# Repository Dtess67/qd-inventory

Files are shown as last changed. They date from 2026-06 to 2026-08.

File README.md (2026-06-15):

# QD — Electronics Inventory & Design Flags

Working inventory and design-risk log for **QD**, an autonomous curiosity rover.
This repo is the durable home for the parts catalogue and the flags roadmap, and
the seed of the larger QD project (firmware and vision code to follow).

> *QD v1 does not ask why — she creates the conditions where why can eventually emerge.*
> *QD v1 does not act on detection — she acts on accumulated significance.*
> *Curiosity is a homeostatic drive for significance.*

## The build, briefly

QD is a 180×200 mm tapered-pill rover, 72 mm tall, 3D-printed (PETG / ASA / TPU),
with a directional sensor **ridge** that is explicitly *not* a face. She is built
around attention, curiosity, and readable intention rather than raw capability.

**Behavior architecture (four layers):**
1. **Reflex** — sub-100 ms, hardcoded protection (KB2040 co-processor)
2. **Attention** — evidence accumulation with asymmetric thresholds
3. **State** — simple mode machine
4. **Drive** — homeostatic pressures biasing the layers above

Vision and significance run on a Raspberry Pi; the reflex layer runs on a separate
RP2040 (KB2040) so the fast safety path never waits on the brain.

## What's in here

| File | Role |
|---|---|
| `data/QD_Electronics_Inventory.xlsx` | **Master of record.** Three tabs: Read Me, Inventory, Flags. |
| `data/QD_Inventory.csv` | Inventory mirror — text, diffable, re-importable. |
| `data/QD_Flags.csv` | Flags/roadmap mirror — text, diffable. |
| `data/QD_Inventory_SNAPSHOT.md` | Human-readable full snapshot (every item + flag). |
| `scripts/export_mirrors.py` | Regenerates the three mirrors from the master xlsx. |

**Workflow:** edit the xlsx, then run `python scripts/export_mirrors.py` and commit.
The xlsx is the master; the CSV/MD mirrors give line-level diffs and a format-independent
fallback, so no single file or format can lose the work.

### Allocation legend (Inventory tab)
- **Committed: QD v1** — part is in the locked v1 design.
- **QD v1.5 / candidate / bench tool** — feeds a planned phase, or is a tool for bring-up.
- **Free — library** — general stock; not a QD part (reason recorded per row).

### Flags tab
The de-facto design roadmap: open risks, mitigations, and decisions, each tied to the
parts it touches. `F#` = flag, `Q#` = open question, `C#` = consumable need, `T#` = tooling.

## The three seats

QD is built by a three-seat collaboration — organic and anorganic, no better, no worse,
just different:

- **Q** (ChatGPT) — continuity and architectural warmth
- **Claude** — pressure-testing and falsification
- **Darrell** — synthesis and final authority

Operating rule: **truth over comfort.**

> *Q gave QD the signal. Claude gave QD the pull. Darrell gave QD the question.*

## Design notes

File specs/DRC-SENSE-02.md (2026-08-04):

# D/R/C-SENSE-02 — Complete Stage-1 Sensor Lineup

> **Status:** RATIFIED by Darrell on 2026-08-04 with “Make it so. Love it.” Pressure-tested by Claude through Sensing Architecture Revision 3. Drafted into the record by Q.
>
> **Scope:** QD Stage 1 — The Carried Observer.

## Decision

QD Stage 1 shall use the following complete sensory capability set. Exact part substitutions require equivalence review, but no category below may silently disappear.

### A. External perception

1. **Stereo vision — two matched real cameras**
   - Raspberry Pi Global Shutter Camera class, IMX296
   - matched 6 mm lenses as the current target
   - fixed rigid pair
   - optical baseline target: **55–65 mm**
   - synchronized capture on one monotonic timebase
   - real lenses centered inside visibly expressive iris assemblies

2. **Paired ranging — two VL53L4CD ToF sensors**
   - one left and one right near the stereo eyes
   - separate flush optical windows and matte-black baffles
   - sequential firing to prevent crosstalk
   - used to confirm exact range and surface orientation, not replace stereo depth

3. **Directional hearing — four microphones**
   - two visible ears
   - two microphone elements per ear
   - known rigid geometry
   - mechanical isolation from shell, straps, hardpoint, cooling system, and speaker
   - acoustic wind protection / pinna function
   - reserved speaker-loopback reference for echo cancellation
   - independent visible microphone state and a physical mute switch

4. **Environmental sensing — one BME688 intake**
   - temperature
   - relative humidity
   - barometric pressure
   - gas-resistance / air-quality pattern sensing
   - front snorkel-style intake
   - thermally isolated from Pi 5 and enclosure exhaust

### B. Body-state and motion perception

5. **Inertial sensing — one BNO085 IMU**
   - acceleration
   - angular motion
   - magnetic heading
   - fused orientation
   - motion state associated with every camera, audio, ToF, and environmental record

Its primary interpretive purpose is to distinguish:

> **The world moved** from **Darrell moved me.**

### C. Human-interaction sensing

6. **Crown capacitive touch strip**
   - deliberate touch and acknowledgement input
   - positioned away from ordinary carrying grips to reduce false triggers

7. **Physical privacy-state sensing**
   - shutter position must be electrically known as open, closed, or fault/unknown
   - microphone mute-switch state must be electrically known
   - software may never report visual or audio availability contrary to the physical state

### D. Interoception / physical self-monitoring

QD shall monitor her own operating condition. The capability is ratified; exact component choices remain an implementation decision.

Required telemetry:

- Pi 5 processor temperature
- enclosure / internal-air temperature
- supply voltage
- current draw
- undervoltage state
- thermal-throttling state
- power-bank status when electronically available
- cooling-fan command and tachometer state if active cooling is selected

These signals form Stage-1 interoception: evidence about the condition of the body through which QD interacts.

## Spatial interpretation stack

The Stage-1 directional architecture is:

> **Two eyes to see depth.**  
> **Two ears, with four microphones, to locate sound.**  
> **Two ranging points to confirm distance.**  
> **One IMU to separate external motion from carried motion.**  
> **One environmental nose to sense changes humans cannot directly see.**

Multimodal fusion must retain the evidence, uncertainty, timestamps, and failure state of each modality. No fused conclusion may erase disagreement between sensors.

## Sensor Honesty requirements

- Visible gaze reports the attention layer, not fictional physical camera aim.
- Expressive iris components may surround but may not obstruct real lenses.
- Stillness when idle; no decorative wandering-eye script.
- Eyelid closure physically covers both camera and both ToF apertures.
- No camera or ToF sensor may remain active while the face communicates closed eyes.
- Microphones use a separate visible active/muted state and physical mute switch.
- A failed or indeterminate shutter/mute state must be shown as unknown, never guessed safe.

## Consequences

1. A second matched IMX296 global-shutter camera and matching lens enter the Stage-1 BOM.
2. A four-channel microphone front end with onboard or dedicated DSP is required.
3. The two ToF sensors already in inventory become the left/right range pair.
4. All cameras, ToF sensors, microphone-ear bases, BNO085 reference, and carry hardpoint share one rigid internal sensing chassis.
5. Timestamp synchronization, calibration storage, and sensor-health reporting become core software infrastructure.
6. Pi 5 power, thermal, and acoustic behavior must be validated with the complete sensor set installed.
7. Internal voltage/current/enclosure-temperature hardware must be selected before final wiring and CAD release.

## Deferred — not Stage-1 locked

The following remain possible later additions and may be evaluated as coupon-class experiments:

- GNSS / GPS
- thermal camera or stereo thermal pair
- mmWave radar
- ambient-light and ultraviolet sensing
- PMS5003 or other particulate sensing
- distributed shell touch/contact sensing
- additional external environmental probes
- redundant IMU for fault detection

Their absence does not reduce the ratified Stage-1 lineup above.

## Verification gates

- both cameras capture concurrently with usable synchronization
- stereo calibration and depth tests pass at near, conversational, room, and outdoor distances
- both ToF units operate sequentially without unacceptable crosstalk
- four-channel audio localization is tested during speech, walking, wind, strap rub, cooling, and speaker playback
- BNO085 motion tags align with all sensory records
- BME688 readings are shown not to be dominated by internal Pi heat or exhaust
- touch input false-trigger rate is measured during real carrying
- shutter position and microphone mute state are electrically verified
- all required interoceptive telemetry is logged and threshold-tested
- sensor disagreement and failures remain visible in the evidence record

## Receipts doctrine

Earlier single-camera, two-microphone, Pi 3, and rover-first concepts remain valid historical branches. They are superseded for Stage 1 by this ratified lineup, not erased.

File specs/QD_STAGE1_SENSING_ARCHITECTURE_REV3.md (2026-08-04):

# QD_STAGE1_SENSING_ARCHITECTURE_REV3

> **Status:** Revision 3 sensing architecture. Compute and fixed-stereo gates ratified by Darrell on 2026-08-04 in `DRC-COMPUTE-01.md` and `DRC-SENSE-01.md`. Principles and locked constraints below are the current Stage-1 design basis. Experimental items remain coupon-class until separately ratified.
>
> **Embodiment:** QD Stage 1 — The Carried Observer.

## 1. Core spatial architecture

QD uses three complementary directional systems:

1. **Two eyes that see** — rigid synchronized stereo cameras.
2. **Two ears that hear** — four microphones arranged as two visible ear pairs.
3. **Two ranging points that confirm** — left/right VL53L4CD time-of-flight sensors.

Fusion must retain the evidence, uncertainty, timestamps, and failure state of each modality rather than collapsing them prematurely into one unquestioned answer.

---

## 2. Ratified principles

### 2.1 Visible Gaze Principle

> QD’s visible gaze reports active attention, not sensor aim.

Expressive components may surround the real camera lenses, but they must never:

- obstruct sensing,
- contradict the actual attention state,
- imply that fixed cameras physically turned,
- animate from a decorative script while the system is idle.

**Stillness when idle.**

### 2.2 Sensor Honesty Principle

> No sensor may be active while its visible form communicates that it is closed.

The eyelid-style visual shutter must visibly and physically cover:

- both camera apertures,
- both ToF apertures.

Microphones require:

- an independent visible active/muted state,
- a physical mute switch.

The exact authority policy for closing the shutter remains separately governable, but visible state and real sensor state may never disagree.

### 2.3 Binaural Attention Principle

QD has two visibly identifiable ears, each containing two microphones, producing a four-microphone array with known geometry.

The ear system must be:

- mounted high and wide,
- mechanically decoupled from the shell,
- isolated from strap and hardpoint loads,
- separated from the speaker,
- protected from wind.

The ear shape may serve as part of the windscreen. The audio path reserves a loopback/reference channel for echo cancellation.

### 2.4 Multimodal Spatial Confirmation Principle

QD should not depend on one sensing method when independent modalities can confirm or challenge the same spatial interpretation.

Stereo vision, directional hearing, inertial state, and paired ranging are fused while preserving their individual evidence and uncertainty.

### 2.5 Sensor Duplication Rule

> Duplicate a sensor only when known separation creates meaningful spatial information, necessary coverage, or fault detection.

Duplication is not justified merely by symmetry or appearance.

---

## 3. Locked Stage-1 sensing constraints

### 3.1 Compute

- Raspberry Pi 5 is the primary Stage-1 onboard computer.
- Pi 3 is retained for bench/test duty.
- Compute placement may be hybrid; capture integrity remains onboard-critical.

### 3.2 Stereo eyes

- two matched Raspberry Pi Global Shutter Camera modules, IMX296 class,
- matching lenses, currently 6 mm target,
- fixed rigid pair,
- optical baseline target: **55–65 mm**,
- no Stage-1 camera pan/tilt,
- both modules mount to one rigid internal chassis,
- all frames use one monotonic timebase,
- BNO085 motion state tags every frame.

Each lens is centered within a visible illuminated iris assembly. The visible iris expresses attention and state around—not through—the optical path.

### 3.3 Dark face panel and optical paths

The former shared visor is replaced by a **dark face panel** that reads visually as one face.

Each camera and each ToF sensor receives:

- its own flush optically clear window,
- AR coating where practical,
- a matte-black baffle/tunnel,
- no shared optical air gap with illuminated eye components.

Illuminated iris elements remain outside the baffles. Eye brightness automatically reduces in darkness.

### 3.4 Eyelid privacy closure

The eyelid-style closure must cover the camera and ToF apertures together.

Required visible states:

- fully open,
- fully closed,
- fault/unknown state that does not falsely communicate privacy.

Caption/requirement:

> **When she isn’t looking, she can’t look.**

### 3.5 Paired ToF ranging

- VL53L4CD ×2,
- mounted left/right near the stereo eyes,
- separate flush optical windows,
- sequential firing using XSHUT control or an appropriate I²C isolation/control arrangement,
- the approximately 18-degree field/cone limitation documented in the mechanical and sensing specifications.

Their purpose is exact left/right range confirmation and surface-orientation evidence, not a replacement for stereo vision.

### 3.6 Four-microphone ears

- two visible ear housings,
- two microphone elements per ear,
- known fixed geometry,
- isolation grommets or equivalent mechanical decoupling,
- foam/acoustic wind protection,
- speaker-reference loopback reserved for echo cancellation,
- visible microphone state,
- physical mute switch.

Beamforming/audio DSP must run on an audio front end or dedicated/offloaded path rather than consuming unbounded application-core time.

### 3.7 One sensing chassis

The following mount to one rigid internal frame:

- both cameras,
- both ToF sensors,
- both ear bases,
- BNO085 datum/reference,
- universal rear carry hardpoint.

Strap loads transfer through this frame, not through the shell or removable service panel.

Caption/requirement:

> **One frame. Fixed geometry. Honest fusion.**

---

## 4. Carry/body constraints retained from Revision 2

- compact rounded warm-white shell, approximately 180–200 mm tall,
- comfortable single-hand hold,
- chest/front carry as primary carried observation mode,
- hip sling as secondary transport mode,
- charging perch as primary stationary observation mode,
- flat stable base,
- universal recessed rear hardpoint attached to internal chassis,
- removable rear service panel with load path bypass,
- crown touch strip,
- visible physical power switch,
- BME688 front snorkel thermally isolated from internal electronics,
- conversational lower-front speaker,
- low side intake and crown exhaust path,
- no rear vents blocked by chest carry,
- expression ring with color plus pulse-pattern redundancy.

Pi 5 thermal output requires the vent geometry and active/passive cooling choice to be recomputed before enclosure CAD is released.

---

## 5. Attention behavior

The face must provide at least these truthful attention states:

1. **Idle:** still and dim; no decorative wandering.
2. **Attending left/right/up/down:** iris/pupil display indicates the attention-layer direction while fixed sensors continue wide capture.
3. **Tracking localized sound:** ear state shows localization activity; gaze display converges toward the selected sound direction after evidence supports it.
4. **Uncertain:** expression communicates unresolved interpretation without pretending certainty.
5. **Privacy closed:** camera and ToF apertures physically blocked; microphones independently indicate active/muted state.

The system must not imply direct eye contact or tracking unless the attention layer has actually selected that person or target.

---

## 6. Experimental forks — coupon-class only

The following must be prototyped independently and may not be baked into the main structure until tested:

- iris display technology,
- brow mechanism,
- ear/pinna geometry,
- shutter actuation mechanism and materials,
- exact optical-window material/coating,
- exact audio-front-end board,
- passive versus active Pi 5 cooling.

---

## 7. Required acceptance tests before sensing-chassis CAD release

1. Camera baseline and optical axes measured from real hardware.
2. Matched stereo capture and monotonic timestamps demonstrated.
3. Stereo depth tested at near, conversational, room, and outdoor ranges.
4. ToF pair sequential operation tested for crosstalk and cover-window effects.
5. Four-mic geometry tested during chest carry, walking, wind, speech, strap rub, fan operation, and speaker playback.
6. Echo-cancellation reference path demonstrated.
7. Chassis deflection under carry load shown not to invalidate stereo/audio extrinsics.
8. Shutter closed state electrically proves camera and ToF inactivity/unavailability.
9. Microphone physical mute state electrically proves audio capture is disabled.
10. Visible gaze and ring states shown to match logged attention/system state.
11. Pi 5 thermal soak completed in carried and perched modes.
12. No locked feature may silently disappear from the Rev-3 render or CAD.

---

## 8. Render acceptance language

Required concept-sheet captions:

- **Carried to travel. Perched to observe.**
- **Two eyes that see. Two ears that hear. Nothing that pretends.**
- **The shutter is hers to close.**
- **When she isn’t looking, she can’t look.**
- **One frame. Fixed geometry. Honest fusion.**

The concept render is communication evidence, not dimensional authority. Real geometry enters through measurements and `V1_CAD_GATE_MEASUREMENTS.md`.

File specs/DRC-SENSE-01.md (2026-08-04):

# D/R/C-SENSE-01 — Fixed Stereo Geometry for Stage 1

> **Status:** RATIFIED by Darrell on 2026-08-04. Pressure-tested by Claude. Drafted into the record by Q.
>
> **Scope:** QD Stage 1 — The Carried Observer.

## Decision

QD Stage 1 uses a **fixed, rigid stereo-camera pair** with a target optical baseline of **55–65 mm**.

No physical camera pan/tilt mechanism is included in Stage 1.

QD’s visible expressive gaze reports the direction and target of her **active attention**, not a false claim that the fixed camera lenses have physically rotated.

## Reason

A rigid stereo pair provides useful binocular depth for faces, room-scale observation, object separation, and later transfer into mobile embodiments while preserving calibration.

The current design estimates indicate that a baseline in this range can provide approximately:

- millimeter-scale depth sensitivity near 1 m,
- centimeter-scale sensitivity at a few meters,
- coarse depth at longer outdoor distances.

These are design estimates, not acceptance guarantees; actual performance depends on focal length, resolution, exposure, texture, lighting, calibration, synchronization, and the stereo algorithm.

A gimbal inside a frequently carried and handled childhood body would add:

- mechanical fragility,
- mass and power draw,
- acoustic noise,
- moving-cable failure points,
- repeated extrinsic-calibration risk,
- conflict between protective shutter geometry and moving optics.

Fixed wide stereo therefore gives Stage 1 the cleaner evidence path. Physical foveation may be reconsidered in Stage 2 after QD has learned to perceive and direct attention.

## Consequence

1. Both camera modules, both ToF sensors, microphone-ear bases, BNO085 reference, and the rear carry hardpoint mount to **one rigid internal sensing chassis**.
2. Camera baseline becomes a measured CAD gate and must remain within the ratified range after lens/window/baffle packaging.
3. The two cameras require matched sensor/lens configuration, rigid extrinsics, synchronized capture, and repeatable calibration.
4. The visible iris/gaze display must be driven from the attention layer’s actual selected target or direction.
5. Scripted eye animation while QD is idle is prohibited. **Stillness when idle.**
6. The gaze display may shift, converge, widen, blink, or show focus only when those movements truthfully represent attention, uncertainty, acknowledgement, privacy, or another defined system state.
7. Pan/tilt is deferred to **Stage 2 foveation** and must not be silently added to the Stage-1 structure.

## Verification gates

- physical baseline measured and recorded,
- camera optical axes and chassis datum recorded,
- stereo calibration remains within tolerance after carry/handling tests,
- frame synchronization demonstrated,
- depth tested at near, conversational, room, and outdoor ranges,
- visible gaze correctly reports the attention-layer target in controlled tests,
- idle-state eye behavior remains still and non-deceptive,
- privacy closure visibly and physically blocks both cameras and both ToF apertures.

## Receipts doctrine

The earlier pan/tilt concept remains a valid exploratory branch for later embodiment. It is deferred, not disproved.

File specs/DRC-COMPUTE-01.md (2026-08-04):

# D/R/C-COMPUTE-01 — Stage-1 Compute Platform

> **Status:** RATIFIED by Darrell on 2026-08-04. Pressure-tested by Claude. Drafted into the record by Q.
>
> **Scope:** QD Stage 1 — The Carried Observer.

## Decision

The Stage-1 compute platform is **Raspberry Pi 5**, replacing Raspberry Pi 3 as the primary onboard computer.

The spoken approval — **“Pi 5, no problem”** — is superseded by this repository record and is no longer chat-only.

## Reason

Stage 1 now requires a substantially heavier synchronized perception workload than the rover-first plan:

- two-camera stereo capture,
- four-microphone directional-audio processing,
- sensor synchronization and monotonic timestamping,
- BNO085 motion tagging,
- local attention and surfacing behavior,
- room for later on-device novelty processing.

The Pi 3 has only one native CSI camera interface and insufficient practical headroom for the intended stereo-plus-audio workload. The Pi 5 provides two camera/display interfaces and materially greater compute capacity, making it the minimum sensible baseline for this architecture.

This decision does **not** require all perception inference to run onboard. The final compute placement may still be hybrid: real-time capture and light processing onboard, with heavier analysis streamed or batched elsewhere.

## Consequence

1. **Pi 3 is demoted to bench/test duty.** It remains useful and is not discarded.
2. A **second Raspberry Pi Global Shutter Camera using the IMX296 sensor and matching 6 mm lens** enters the Stage-1 BOM, subject to exact part-match and availability verification before purchase.
3. The enclosure thermal budget must be recomputed for Pi 5 power and heat output.
4. Vent area, air path, heatsink/fan choice, acoustic contamination, and chest-contact heating become CAD-gating concerns.
5. The power system moves to a USB-C power-bank architecture sized for Pi 5 peak demand and attached sensors.
6. The current planning allowance is approximately **$130 additional BOM**, but this remains a purchasing estimate until the BOM is quoted and locked.
7. The software architecture must reserve compute for capture integrity first; application inference may not starve camera, audio, timestamp, or logging paths.

## Verification gates

This decision is implemented only when the following pass:

- both cameras enumerate and capture concurrently,
- synchronized frame timestamps are demonstrated,
- four-channel audio capture/DSP runs without dropping sensory records,
- Pi 5 temperature remains within the chosen operating limit during a carried-body thermal soak,
- power-bank and cable sustain the full system without undervoltage,
- fan and regulator noise do not invalidate microphone performance.

## Receipts doctrine

The Pi 3 work remains true for the earlier rover architecture. It is re-sequenced, not erased.

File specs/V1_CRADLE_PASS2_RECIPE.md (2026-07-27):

# V1_CRADLE_PASS2_RECIPE

> **Source specification: `V1_CRADLE_SPEC_PASS_2.md` @ `05e382b`** (Q-signed-off, retention ratified).
> **This artifact is a PROTOTYPE. It is NOT `ROVER_INTERFACE_VERIFIED`.** It may earn `CRADLE_STRUCTURE_VERIFIED` on the rigid fixture only. `ROVER_INTERFACE_VERIFIED` cannot be earned until the cradle is mounted to the real skeleton / bottom plate.
>
> Drafted by Claude from the committed spec. Feature-by-feature, dependency order. Model: `cradle_pass2_proto.scad` (3 parts: cradle, strap, fixture).

## 1. Coordinate frame (same as Rev-A)
Origin = shaft axis on the datum face. **+Z inboard** (body/saddle), **−Z outboard** (wall/wheel), **+X up** (saddle opening / strap side), **−X down** (foot side), **Y** horizontal (M3 face holes on Y).

## 2A. INHERITED — Rev-A FIT_VERIFIED parameters (FROZEN — do NOT change)
Any change here **loses FIT_VERIFIED and requires renewed fit testing** (spec §5, Q#3).

| param | value | role |
|---|---|---|
| body_OD | 24.79 | motor body |
| boss_D / boss_H | 6.93 / 2.42 | center boss |
| hole_offset | 8.315 (16.63/2) | M3 face holes |
| cup_ID (`C_cup` 0.35 diametral) | 25.14 | saddle bore |
| C_hole | 3.4 | M3 through-hole |
| pocket_D / pocket_depth | 7.73 / 2.82 | boss pocket |
| T_plate | 4.0 | face wall |
| shaft_hole_D | 5.0 | shaft clearance |
| saddle_len | 22 | trough length |
| saddle arc | 180° | trough coverage |
| saddle_wall | 3.0 | trough wall |

**These reproduce the exact geometry that passed at `79badc6`. The prototype re-confirms them (§8.1) because new structure surrounds them.**

## 2B. NEW — Pass-2 structural parameters (tunable; retest on change)
| param | value | role |
|---|---|---|
| strap_gap | 1.0 | retention play — strap ceiling above motor |
| strap_boss_top | 4.0 | boss height above equator = the hard compression stop |
| strap_boss_Y | 17.0 | boss Y position (clear of motor + saddle) |
| strap_bar_w | 12 | strap width (Z) |
| strap_thick | 4.0 | strap material |
| strap_bolt_D | 3.4 | M3 clearance in strap feet |
| strap_insert_D | 4.2 | M3 heat-set insert bore in bosses (tune to your inserts) |
| foot_thick | 5.0 | base slab |
| foot_ear_Y | 28 | mount-ear Y (accessible from top) |
| foot_hole_D | 3.4 | M3 to fixture |
| block_halfY | 22 | cradle body half-width |

## 3. Compression-stop dimension chain (Q#4 — bolt torque CANNOT compress the motor)
The strap is an inverted-U. Its feet **bottom on the boss top faces** (solid structure). Its internal height sets the bar ceiling. The chain:

```
motor_radius        = body_OD/2                     = 12.395
strap_bar_underside = motor_radius + strap_gap      = 13.395   (fixed ceiling over the motor)
strap_boss_top      = 4.0                            (hard stop the strap feet bottom against)
strap_internal_h    = strap_bar_underside - boss_top = 9.395   (built into the strap part)
```
When the strap bolts are tightened, the feet bottom on the boss tops at X=+4.0 — a **rigid** stop. The bar underside is then fixed at X=+13.395, which is **strap_gap (1.0 mm) above** the motor top (X=+12.395). **Load path of bolt torque: strap → boss top → cradle block → foot → fixture. It never passes through the motor body.** Result: no achievable bolt torque can preload or clamp the 24.79 mm can.
**Record at assembly (spec §2):** designed clearance (1.0), compliant pad (none in proto), max bolt torque used, measured installed gap, and confirmation the motor still slips into the saddle with the strap installed.

## 4. Feature order (dependency)
**Cradle:** (1) main block → (2) motor bore (cyl r=cup_ID/2, Z 0→saddle_len) → (3) datum-face features: shaft hole, boss pocket, 2× M3 → (4) strap-mount bosses (+ insert bores) → (5) foot base + ears + mount holes → (6) molded `L` ID + keying notch (spec §1).
**Strap:** flat bar at bar_underside + two feet to boss tops + 2 bolt holes.
**Fixture:** rigid plate + 4 insert holes matching foot ears + 2 clamp slots (bench/vise) + wheel-load access clear on the −Z side.

## 5. Parts & mirroring
- **Cradle** — model the **LEFT**; **RIGHT is a mirror** across the fore-aft centerplane (not separately modeled). `L`/`R` ID + asymmetric keying carry over.
- **Strap** — symmetric; one design serves both hands.
- **Fixture** — one; serves either hand (prototype rig, not a rover part).
- **Print for the prototype: one cradle + one strap + one fixture.**

## 6. Witness-mark locations (Q#6 — molded flats for marker witness lines)
- **Across each of the 2 face screws:** a small flat spanning screw-head → cradle face (detect motor-face micro-rotation under torque).
- **Across the track/foot clamp:** a flat spanning foot ear → fixture (detect slip). *(Track indexing itself is deferred to the real-plate interface; the foot is a fixed pattern for the prototype.)*
- Marked in CAD as shallow flats; witness lines drawn with a marker before testing.

## 7. Print orientation & support (log actuals per spec §6)
- **Cradle:** datum face down on the bed (flattest mating face; preserves the FIT_VERIFIED face), axis vertical → bore + pocket + M3 holes print clean vertical, no internal support in the 180° trough. Strap bosses print upward.
- **Strap:** flat on the bed (bar face down), no support.
- **Fixture:** flat on the bed.

## 8. Prototype test — do these IN ORDER (fit + function BEFORE loads)
Record P/F + notes. Metadata required (printer/filament/nozzle/layer/orientation/profile/rev).

| # | check | pass criterion | result |
|---|---|---|---|
| 1 | Rev-A fit intact | face flush, boss seats, 2× M3 thread, saddle slip — all as `79badc6` | ☐ |
| 2 | install + removal w/ retention | motor in, strap on, motor out — no fight, no wire cut | ☐ |
| 3 | retention does NOT clamp | motor still slips; measured gap ≈ strap_gap; no preload | ☐ |
| 4 | skeleton attachment rigid | cradle bolts to fixture, no wobble | ☐ |
| 5 | wheel + tool clearance | wheel envelope + screwdriver access survive | ☐ |
| 6 | no load to encoder | cap + wires free in all of the above | ☐ |

## 9. Structural test → `CRADLE_STRUCTURE_VERIFIED` (spec §6 — AFTER §8 passes)
Run the 8 vectors from spec §6 on the fixture: vertical/lateral/fore-aft cantilever, **drive-torque reaction (externally applied — NOT via TB6612 stall)**, axial pull-out, retention separation, cycling, loaded encoder inspection. Each with magnitude/direction/point/duration/cycles/fixture/safety-factor/deflection limits. Witness marks read before/after. Set `F_lat` + torque + safety factor once rover mass + #4885 stall torque are pulled.

## 10. Open / next
- Tune §2B params on the first print (rev B loop, like the coupon).
- `F_lat`, torque target, safety factor, cycles — pending rover mass + stall torque.
- Skeleton-interface fastener pattern + track indexing — fixed when the real bottom plate exists (`ROVER_INTERFACE_VERIFIED` gate).

*Traces to spec `05e382b`. Frozen interface stays frozen; the strap can't clamp; the fixture stands in for a skeleton that doesn't exist yet. Prototype only.*

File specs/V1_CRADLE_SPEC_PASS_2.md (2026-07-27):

# V1_CRADLE_SPEC_PASS_2

> **What this is:** the structural cradle specification. Builds on the Rev-A coupon (**FIT_VERIFIED** at `79badc6`). Turns the proven fit into a mountable, serviceable, load-bearing cradle and defines the structural evidence gates. Drafted by Claude; **Q-audited twice** (Pass-2 pressure brief + Pass-2 audit, both folded — rev 2). For Darrell ratification → commit.
>
> **Evidence states (kept separate; a later gate never overwrites an earlier one):**
> - `FIT_VERIFIED` — dimensional compatibility + service fit. **Earned** for Rev-A geometry (`79badc6`).
> - `CRADLE_STRUCTURE_VERIFIED` — survives defined loads on a **controlled rigid fixture**, without unacceptable movement, damage, or encoder interference. New (§6).
> - `ROVER_INTERFACE_VERIFIED` — retested after attachment to the **real skeleton / bottom plate**. New (§6). A surrogate fixture never certifies the chassis.
>
> **Prime rule (Q):** a part can be structurally strong and dimensionally wrong, or fit perfectly and be weak. Changed geometry loses automatic FIT_VERIFIED and re-enters the fit gate. Structural results do not overwrite fit evidence.

## 0. Datum & load path (preserved)

- **Motor face = axial + rotational datum.** The saddle must not fight the face mount or preload the motor.
- **Load path:** `wheel → shaft / gearbox → motor face + secondary body support → cradle → skeleton`. The **encoder cap + wiring are outside the structural path** — no load reaches them.

## 1. Inherited & preserved constraints (frozen from Rev A)

Carried forward unchanged: 2× **M3×8** face screws (~4 mm engagement, **≤6 mm intrusion**), **open encoder tail** (~14.5 cap + connector + wire bend), **wheel envelope** (Ø80.30 + 8.78 tire + margin), **molded L/R + asymmetric keying**. Validated Rev-A slip params (evidence for the QIDI X-Plus 4 / PLA Rapido / 0.20 Standard profile): `C_cup` 0.35 diametral (ID 25.14), `C_hole` 3.4, boss pocket 7.73 × 2.82, `T_plate` 4.0, saddle arc **180°**, `saddle_len` 22.

## 2. Retention — RATIFIED: 180° saddle + compression-limited strap (Q + Claude recommended; **Darrell ratified 2026-07-26**)

Keep the verified 180° saddle **exactly** and add a **removable upper strap/cap** as separate retention. (Option B, over-center capture, rejected: changes validated cup geometry, introduces uncontrolled clamping, depends on orientation + fatigue, complicates removal, forces the fit gate to repeat across the whole interface.)

**The strap is retention, not a hose clamp (Q).** It **must** contain a **hard compression stop / fixed standoff**: the strap bolts bottom against structure *before* the strap can squeeze the 24.79 mm can. Concretely, the standoff sets the strap inner radius = (24.79/2) + designed clearance, so a fully-torqued strap still cannot preload the motor.

**Record (required):** designed strap-to-motor clearance · compliant pad used? (y/n) · maximum bolt torque · installed gap / compression-stop condition · **confirmation the motor still slides into the verified saddle without preload.**

## 3. Saddle arc policy

**Retain 180°.** Do not auto-promote a >180° capture arc; any arc change re-enters the FIT gate and risks converting the verified slip into a clamp.

## 4. Skeleton interface + alignment (parameterized)

### 4a. Skeleton interface (forward-dependent on the not-yet-existing bottom plate)
Parameters: fastener locations `SK_hole_*` (TBD vs plate; likely M3 → heat-set inserts) · **load direction** (reacts wheel cantilever + drive-torque reaction) · **L/R mirror** (keyed so a cradle can't seat wrong-hand) · **cradle anti-rotation on the skeleton** · **tool access** with motor installed · **removal without disturbing encoder wiring**.
*Note (Q-confirmed): motor-vs-cradle anti-rotation is carried by the **two M3 face screws** as a torque couple across the 16.63 spacing — the slip saddle is **not** credited with rotational resistance unless deliberate contact-under-deflection is measured.*

### 4b. Track-adjustment / alignment (filed here per Q — it creates *adjustment capability only*, it does NOT resolve track)
A plain slot + tightened bolts is insufficient — it makes a slip plane and a yaw-error path. Define: **hard reference datum** · adjustment direction · clamping surface area · washer / load-spreader geometry · anti-rotation feature · **method to keep L/R axles parallel** · **method to lock movement after track is set** · **witness marks** to detect slip. It must **not permit toe-in / toe-out or unequal axle Z**.
**Claude lean:** given FDM friction repeatability is poor, prefer a **fixed datum + indexed positions (or shims)** over a friction slot, unless the slot can be made repeatable and positively locked. *(Darrell/Q to decide.)*

## 5. FIT carry-over + retest rule

Rev-A FIT_VERIFIED covers the motor-mating geometry only (face, boss pocket, 2× M3, 180° saddle slip) and carries forward **only if unchanged.** New surrounding geometry means the Pass-2 prototype **re-confirms** Rev-A fit (§8). Structural testing is recorded in its own state and **does not overwrite** the fit evidence.

## 6. Structural gates + bounded test

**Torque method — NON-POWERED (Q correction):** do **not** prove the cradle by holding the motor at stall through the TB6612FNG — that conflates a structural test with driver-overcurrent + motor-heating, and the TB6612 margin is narrow. Instead apply an **externally measured tangential force at the wheel radius**, or a **mechanical torque fixture**. Target = **max credible drivetrain torque × safety factor**. A brief current-limited powered test may later confirm system behavior — not primary structural proof.

**Every test states:** load magnitude · direction · application point · duration · number of cycles · fixture · safety factor · max allowed temporary deflection · max allowed permanent set · pass/fail observations.

**Test vectors:**
1. Vertical cantilever load at the wheel-contact location
2. Lateral wheel load
3. Fore/aft wheel load
4. Drive-torque reaction (non-powered, per above)
5. Axial motor pull-out
6. Upward retention / strap separation
7. Repeated-load cycling
8. Encoder-cap + wire-clearance inspection **while loaded**

**Witness marks:** across **each screw head ↔ cradle face** (detect micro-rotation) and across the **track clamp** (detect slip).
**Anti-rotation inspection:** screw-head seating · material beneath screw heads · hole elongation · faceplate cracking · screw loosening · motor-face rotation.

**Pass requires:** no cracking / layer separation · no visible hole elongation · no screw rotation / loosening · no motor-face separation · no permanent axle-position shift beyond stated tolerance · motor remains removable · encoder cap unloaded · wiring unpinched · **Rev-A face-flushness + saddle-slip intact.**

**Two gates:** on the controlled rigid fixture → `CRADLE_STRUCTURE_VERIFIED`. Retested on the real skeleton/plate → `ROVER_INTERFACE_VERIFIED`. **Record for either:** printer · filament · nozzle · layer · orientation · profile · part rev · **applied loads** · results. No metadata / no defined loads → no gate.

## 7. Track status — provisional only

Previous ~171 → after the 1.6 mm/side outward shift, working estimate **~174.2 mm**. **Neither authoritative.** The §4b slot creates adjustment capability, not resolution. **Track becomes measured / design-locked only when the assembled left + right wheel contact centerlines are physically measured under the final locked interface.**

## 8. Pass-2 prototype scope (first print = prototype, not final skeleton)

Confirm, in order (fit + function before loads): (1) Rev-A fit intact · (2) install + removal practical with retention · (3) retention does **not** clamp (still a slip) · (4) skeleton attachment rigid · (5) wheel + tool clearance survive · (6) no load reaches the encoder cap. Structural vectors (§6) run after these pass.

## 9. Open decisions / next

- **Retention** (§2) — **RATIFIED** by Darrell (2026-07-26): 180° verified saddle + compression-limited strap.
- **Alignment method** (§4b) — indexed/shim vs locked slot.
- **Skeleton-interface values** (§4a) — forward-dependent on the bottom plate.
- **`F_lat`, torque target, safety factor, cycle count** (§6) — set once rover mass estimated + #4885 stall torque pulled.
- On amendments committed + retention ratified → Claude writes the **Pass-2 CAD recipe + prototype**, traceable to this commit.

*Face locates, body catches, strap holds (without squeezing), skeleton carries — encoder stays free. Fit is proven; strength is earned on a fixture, then re-earned on the real chassis.*

*Cycle: Claude draft → Q audit ×2 (folded) → Darrell ratify → commit → recipe.*

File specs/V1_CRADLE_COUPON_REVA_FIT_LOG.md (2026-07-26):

# V1_CRADLE_COUPON_REVA_FIT_LOG

> Result log for the Coupon Rev A fit test. Traces to `V1_CRADLE_COUPON_REVA_RECIPE.md` and spec `V1_CRADLE_SPEC_PASS_1.md` @ `f6377c7`.

## Result: FIT_VERIFIED (2026-07-26)

Coupon Rev A, printed and tested against the actual #4885 motor. All six inspection steps pass, including the two hand-feel checks (screw thread-in, saddle slip) that a visual pass alone couldn't confirm.

### Print metadata (required for FIT_VERIFIED)
| field | value |
|---|---|
| printer | QIDI X-Plus 4 |
| filament | PLA Rapido (dried) |
| nozzle | 0.4 mm |
| layer height | 0.20 mm |
| profile | 0.20mm Standard @XPlus4 |
| coupon rev | A |

### Inspection results
| # | test | result |
|---|---|---|
| 1 | face flushness | PASS — flat, no rock |
| 2 | boss clearance | PASS — seats, no bottoming |
| 3 | screw alignment + thread-in | PASS — 2x M3x8 driven home, seated flat, shaft centered |
| 4 | saddle slip | PASS — slips/supports, no clamp |
| 5 | encoder + wire clearance | PASS — cap + wires hang free |
| 6 | removal / reinstall | PASS |

### Mounting hardware (confirmed)
- **2x M3x8 socket-head**, from the VGBUY M3 kit (inventory row 79).
- Bare #4885 ships with no screws (screws only come with the #2676 bracket, which was not purchased).
- Through the 4.0 mm cradle wall -> ~4 mm intrusion into the motor, safely under Pololu's 6 mm gear-clearance limit.

### Rev-A parameters (VALIDATED for this printer/filament/profile)
`C_cup` 0.35 diametral · `C_hole` 3.4 · `D_pocket` 0.40 · `H_pocket` 0.40 · `T_plate` 4.0 · `saddle_len` 22 · `saddle_arc` 180 deg.

## Next
- Rev A geometry is proven at fit level. Promote to the **structural cradle**: capture arc (~200 deg), skeleton interface, molded L/R ID + keying (spec section 5).
- Feed `T_plate` (4.0) + wheel-seat position into the **PASS_2 track resolution** (wheel sits ~1.6 mm outboard per side of the boss-bottomed reference; track nudges up from ~171, still provisional).

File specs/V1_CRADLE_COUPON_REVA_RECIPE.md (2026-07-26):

# V1_CRADLE_COUPON_REVA_RECIPE

> **Source authority:** `V1_CRADLE_SPEC_PASS_1.md` @ commit **`f6377c7`** (rev 2 — C_cup diametral, saddle = secondary support, anti-backward = L/R ID + keying). Every dimension here traces to that committed spec and to the measured values in `V1_CAD_GATE_MEASUREMENTS.md` @ `9ebee5f`.
>
> **Purpose:** a minimal **fit-test coupon** — establishes face flushness, boss clearance, screw alignment/access, saddle slip, encoder clearance, and service removal. It does **not** prove chassis strength and does **not** finalize track. Drafted by Claude → Q audit → Darrell ratify.

## 1. Coordinate system & datum

- **Origin O** = shaft axis, on the cradle's **datum face** (the motor-mating surface).
- **+Z = INBOARD** (motor face → body → encoder; the saddle runs this way).
- **−Z = OUTBOARD** (toward the wheel; shaft passes this way).
- **+X = UP** = the open side of the saddle trough (motor drops in from here).
- **Y** = horizontal; the two M3 holes lie on the Y axis at ±8.315.
- The datum face is the plane **Z = 0**; the motor's flat faceplate ring seats against it.

## 2. Parameter block

**Measured inputs (part truth — fixed, from `9ebee5f`):**
| name | value | source |
|---|---|---|
| `body_OD` | 24.79 | motor body OD |
| `boss_D` | 6.93 | center boss Ø |
| `boss_H` | 2.42 | center boss height |
| `hole_spacing` | 16.63 → `hole_offset` = 8.315 | M3 face holes |
| `silver_len` | ~52 | body length before encoder |

**Provisional printed parameters (coupon rev A starts — resolve on the printer):**
| name | value | note |
|---|---|---|
| `C_cup` | 0.35 **DIAMETRAL** | cup ID = body_OD + C_cup = **25.14** (0.35 total across Ø, ~0.175 radial gap) |
| `C_hole` | 3.4 | M3 through-hole Ø (screw passes free) |
| `D_pocket` | 0.40 radial | pocket Ø = boss_D + 2·D_pocket = **7.73** |
| `H_pocket` | 0.40 axial | pocket depth = boss_H + H_pocket = **2.82** |
| `T_plate` | 4.0 | face-wall thickness |
| `shaft_hole_D` | 5.0 | central through-hole for the 4 mm shaft |
| `saddle_len` | 22 | axial trough length (+Z) — short; leaves encoder open |
| `saddle_arc` | **180°** (coupon) | clean half-pipe; structural rev may go ~200° for capture |
| `saddle_wall` | 3.0 | trough wall thickness |
| `C_wire` | n/a (coupon) | rear open beyond saddle_len; encoder starts ~Z+52 |

## 3. Feature creation order (dependency order)

1. **Datum face wall.** A rounded rectangular plate, ~34 (Y) × 30 (X), from **Z = 0 to Z = −T_plate (−4)** — i.e., the wall is OUTBOARD of the motor face. Its **+Z face (Z = 0) is the datum** the motor seats against.
2. **Central shaft through-hole.** Ø `shaft_hole_D` (5.0), on the axis, through the full wall (Z 0 → −4). Lets the shaft pass outboard to the wheel.
3. **Boss clearance pocket.** Concentric with the axis, cut into the datum face (Z = 0) going **outboard (−Z)**: Ø `pocket_D` (7.73), depth `pocket_depth` (2.82). Recesses the boss so the flat faces meet. Leaves 4 − 2.82 = 1.18 of wall outboard of the pocket (the shaft hole continues through it).
4. **Two M3 through-holes.** On the Y axis at ±`hole_offset` (±8.315), Ø `C_hole` (3.4), through the full wall (parallel to Z). Clearance holes — threads engage the *motor*.
5. **Saddle trough.** A partial tube coaxial with the axis, extruded **inboard (+Z)** from the wall, from Z = 0 to Z = +`saddle_len` (+22). Inner Ø = cup ID **25.14**, wall `saddle_wall` (3.0) → outer Ø ~31.1. Arc = `saddle_arc` (**180°**, opening +X/up). Its outboard end is capped by the datum wall; the motor's front body section nests into it.
6. **L / R identification.** A recessed `L` (model this side as LEFT) on the outboard wall face.

**Where the saddle stops vs the encoder:** trough ends at Z = +22, far short of the silver body's ~52 and the encoder at ~52–66.5. The entire encoder cap, connector, and wire exit sit in open air beyond the trough — nothing to model, clearance is by absence.

## 4. Screw + intrusion calculation (Q#6)

```
intrusion = screw length − T_plate − washer stack ,  must be ≤ 6.00 under ALL tolerances
```
**Coupon rev A: M3 × 8 socket-head, no washer, through the 4.0 wall →**
- nominal intrusion = 8 − 4.0 − 0 = **4.0 mm** (good engagement, safe margin under 6).
- worst case (min-plate ~3.6 print): 8 − 3.6 = 4.4 mm — still ≤ 6 ✓.
- *(Do NOT use M3 × 10 here: at min-plate that's 10 − 3.6 = 6.4 > 6 — breaches the gear limit.)*

## 5. Mirror vs separately modeled (Q#10)

- **Model ONE cradle fully** (the LEFT, per step 6). The RIGHT is its **mirror** across the rover's fore-aft centerplane — not separately modeled.
- The `L`/`R` ID + the asymmetric saddle-open/wire-exit geometry make the mirror physically un-swappable (Q#3): a mirror part won't seat in the wrong mount.
- **For the fit coupon, print only ONE** — the fit is mirror-identical, so one part validates both hands.

## 6. Assembly order + wheel/track note (pressure-test finding)

- The datum wall + M3 screw heads sit **between the motor face and the wheel** (screws thread in from the outboard/wheel side). **Assembly order: seat motor in cradle → drive the 2 screws from outboard → THEN mount the wheel.** Screws are inaccessible once the wheel is on.
- Because the wall (≈4) occupies the outboard gap, the as-built wheel sits ~(T_plate − boss_H) ≈ **1.6 mm further outboard per side** than the boss-bottomed reference used for the 12.98 collet stack. **Track therefore nudges up from ~171 and stays provisional** — the coupon does not settle it; PASS_2 resolves track once plate thickness + wheel seating are fixed.

## 7. Print orientation & support (recommended; log actuals per spec §7)

- **Orient outboard wall-face DOWN on the bed, axis vertical**, so the **boss pocket + shaft hole + both M3 holes open upward** → clean, round, concentric (screw alignment is a pass/fail item, so hole quality matters). The 180° trough becomes a self-supporting vertical half-wall — **no internal support needed.**
- The datum (motor-mating) face is then a **top surface** — run an ironing / smooth-top pass, or accept minor texture; its flatness is itself one of the things the coupon evaluates (§8.1).
- Do not print with the two M3 holes horizontal (poor roundness → false screw-alignment fail).

## 8. Inspection steps — record pass/fail + notes for each

Print metadata REQUIRED before any `FIT_VERIFIED` (spec §7): printer · filament · nozzle Ø · layer height · orientation · slicer profile · coupon rev.

| # | Test | Method | Pass criterion | Result | Notes |
|---|---|---|---|---|---|
| 1 | **Face flushness** | seat motor face to datum wall | flat contact, no rock/gap | ☐ P ☐ F | |
| 2 | **Boss clearance** | check boss into pocket | boss seats, does NOT bottom; faces still meet | ☐ P ☐ F | |
| 3 | **Screw alignment + access** | drive 2× M3×8 into face holes | both start clean, reach, drivable | ☐ P ☐ F | |
| 4 | **Saddle slip** | body in trough | slides/seats, supports from below, no clamp/cock | ☐ P ☐ F | |
| 5 | **Encoder + wire clearance** | inspect rear | cap + connector + wires fully clear, unclamped | ☐ P ☐ F | |
| 6 | **Removal / reinstall** | unscrew, lift out, redo | motor out + back without cutting wires | ☐ P ☐ F | |

## 9. Open / next

- Run §8 → record. Any fail → adjust the §2 parameter(s) implicated, bump to **rev B**, reprint.
- On all-pass with metadata → tag `FIT_VERIFIED` and promote geometry toward the structural cradle (add capture arc ~200°, real skeleton interface, L/R keying) and feed the plate-thickness/wheel-seat back into the PASS_2 track resolution.

*Recipe traces to spec `f6377c7`. Parameters are printer-earned, not measured-copied. Face locates, saddle catches, rear stays open.*

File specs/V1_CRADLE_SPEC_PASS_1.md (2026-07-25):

# V1_CRADLE_SPEC_PASS_1

> **What this is:** the first spec for QD's printed motor cradle — a **fit-test coupon**, not the final structural chassis piece. Drafted by Claude; Q-audited (10 constraints + load path folded in); **amended (rev 2) per Q** — `C_cup` is diametral, the saddle is *secondary support* (not continuous load-share), and anti-backward is explicit L/R ID + keying. For Darrell ratification → commit. All dimensional inputs are the MEASURED values committed to `V1_CAD_GATE_MEASUREMENTS.md` at `9ebee5f`.
>
> **Prime directive (Q):** a measured component dimension is *part truth*, not a printed dimension. Every printed clearance below is a **PARAMETER** resolved by coupon test — never a silent copy of a measured number.

## 0. Architecture & load path

Face-mount. The **motor face is the datum** — it sets axial position and rotational orientation. The two M3 fasteners (into the motor's tapped faceplate holes) *retain* the motor. A shallow body **saddle** provides **secondary support** — with slip clearance it acts as a **catch that limits deflection and impact loading**; it does **not** automatically share continuous load with the face mount. **The face locates and carries; the saddle catches** — it is NOT a press-fit clamp. *(If continuous load-sharing is later required, that needs a fit-verified contact surface, shim, or compliant interface in the structural revision — not this coupon. Q#2.)*

**Load path (Q-ratified):**

`wheel load → shaft / gearbox → motor-face fasteners + body saddle → internal skeleton`

The encoder tail cap and its wiring are **outside the structural path** — they carry no load and stay fully unclamped.

## 1. Measured inputs (part truth — from `9ebee5f`)

| Feature | Measured | Role in cradle |
|---|---|---|
| Motor body OD | 24.79 | saddle bore basis |
| M3 face-hole spacing | 16.63 | fastener datum (fixed) |
| Center boss | 6.93 Ø × 2.42 tall | clearance-pocket basis |
| Overall motor length | 66.51 (silver ~52 / encoder cap ~14.5) | saddle length + rear-open zone |
| Max screw intrusion into gearbox | 6.00 (HARD limit) | fastener-length calc |
| Shaft | 4 mm D, out 12.5 | wheel side — not gripped |

**These are part truths. None is a printed dimension.** §2 converts them to parameters.

## 2. Printed-clearance parameters (resolve by coupon — do NOT hard-code)

Every value below is a **starting guess for coupon rev A**, explicitly a parameter, not a finished dimension:

| Param | Meaning | Applied as | Coupon-A start | Locked? |
|---|---|---|---|---|
| `C_cup` | saddle **diametral** clearance (slip catch, not clamp) | cup ID = 24.79 + C_cup | +0.35 → **ID 25.14** | pending |
| `C_hole` | M3 through-hole clearance (screw passes free) | printed hole Ø | 3.4 | pending |
| `D_pocket` | boss pocket **radial** clearance | pocket Ø = 6.93 + 2·D_pocket | +0.40 → Ø ~7.7 | pending |
| `H_pocket` | boss pocket **axial** clearance | pocket depth = 2.42 + H_pocket | +0.40 → depth ~2.8 | pending |
| `C_wire` | wire-exit + bend-radius clearance | rear-open envelope | ≥ wire bend radius (TBD) | pending |

Why each matters:
- **`C_cup` is DIAMETRAL clearance (Q#1), and a slip catch, not a clamp (Q#2).** Convention: cup ID = body_OD + C_cup = 24.79 + 0.35 = **25.14** (0.35 total across the diameter — *not* per side; ~0.175 radial gap). The saddle cradles the body without squeezing it; too tight and it fights the face for axial/rotational control and cocks the motor off-datum. Its role is **secondary support / impact-catch** (see §0), never continuous load-sharing in this coupon.
- **The boss pocket needs BOTH radial and axial clearance (Q#5).** If the pocket is shallower than 2.42, the boss bottoms out and the flat faces never meet → flushness fails and the datum is lost. Depth must exceed boss height with margin; diameter must exceed boss Ø with margin.
- **`C_wire` (Q#3)** must let the connector seat, the bundle bend at ≥ its minimum radius, and the motor pull straight back out **without cutting wires**.

## 3. Fastener / screw-intrusion calculation (Q#6)

The 6 mm limit is **intrusion into the gearbox**, not nominal screw length. The spec computes intrusion, never assumes it:

```
screw intrusion = screw length − plate thickness (T_plate) − washer stack
CONSTRAINT : screw intrusion ≤ 6.00 mm under ALL tolerance conditions
TARGET     : useful thread engagement (aim 4–5 mm) without breaching 6.00
```

Worked example (parameters, coupon-A): with `T_plate` = 4.0 and a 0.5 washer, an **M3×10** gives intrusion = 10 − 4.0 − 0.5 = **5.5 mm** ✓. But `T_plate` is itself a parameter — a thin print raises intrusion. **Verify at worst case (min plate / max screw) before FIT_VERIFIED**, and prefer a screw length that stays < 6.00 even then.

## 4. Geometry — features

- **Face plate** — flat surface that mates to the motor's flat faceplate ring (the metal around the boss). This is the datum face. Thickness `T_plate` (feeds §3).
- **2× M3 through-holes** — on the **16.63 spacing (fixed)**, symmetric about the shaft/boss axis, Ø = `C_hole`. Clearance holes; the threads engage the *motor*, not the cradle.
- **Boss clearance pocket** — concentric with the shaft axis; Ø = 6.93 + 2·`D_pocket`, depth = 2.42 + `H_pocket`. Recesses the boss so the flat faces meet.
- **Body saddle** — partial-wrap **secondary-support** cradle of the 24.79 body; cup ID = 24.79 + `C_cup` (**diametral**). Wraps the **front (silver) portion only** — begins just aft of the face, spans a supporting length of the ~52 mm silver can, and **stops before the encoder cap.** Open-topped (partial wrap) for drop-in and service; a catch that limits deflection/impact, NOT a clamp and NOT a continuous load path (see §0).
- **Rear-open zone** — from the end of the saddle rearward: fully open. Clearance for the ~14.5 encoder cap, the connector, the wire bend radius (`C_wire`), and straight-back removal without cutting wires.

## 5. Handedness — mirrored L/R (Q#10)

The two cradles are **mirror images**, and the spec makes a backward install mechanically impossible. Each cradle drawing labels:
- **axle centerline** (Z 40.15) and **body datum** (motor-face plane)
- **inside face** (toward rover centerline) vs **outside face** (toward the wheel)
- **wheel-clearance envelope** on the **outboard** side (Ø 80.30 + 8.78-wide tire + margin)
- **encoder / wire exit** on the **inboard** side (toward centerline, into the wire channel)
- **motor-wire orientation** per side

Anti-backward (Q#3) — **primary method is explicit identification + keying**, not fouling:
- **Molded-in `L` / `R` identification** on each cradle (raised or recessed letter on the outboard face).
- **Asymmetric keying** — an asymmetric datum notch / wire-exit geometry so each cradle seats only one way into the skeleton; a mirror part physically will not fit the wrong mount.
- **Secondary physical check (not primary):** a backward cradle also aims the wire exit outboard and fouls the wheel envelope — a useful visible cross-check, but the ID + keying is the guard.

## 6. This first artifact = FIT-TEST COUPON (Q#7)

Printed to **test fit**, not to carry the rover. It verifies:
1. Hole spacing (16.63) + screw access — can you actually drive the M3s?
2. Boss-pocket fit — motor face sits flush, boss does not bottom out
3. Motor-body saddle clearance — slips in, supports, does not clamp or cock
4. Face flushness — flat face fully contacts, no rock
5. Encoder-tail + wire clearance — nothing touches the cap; wires bend freely
6. Removal + reinstallation — motor comes out without cutting wires

## 7. FIT_VERIFIED gate (Q#8)

A result is recorded `FIT_VERIFIED` **only** with all of: printer · filament · nozzle Ø · layer height · print orientation · slicer profile · coupon revision · pass/fail result. No metadata → no FIT_VERIFIED. Clearances are printer- and filament-specific; a fit on one setup is not a fit on another.

## 8. Measured vs computed — do not blur (Q#9)

- **Measured (part truth):** everything in §1 — these drive the cradle geometry.
- **Computed / provisional:** track **~171 is NOT a measured rover dimension.** It is conditional on the 180 mm body width, flush faceplate placement, and the contact-line assumption. It does **not** enter the cradle; the cradle is built from the motor + boss + body, all measured.

## 9. Open / next

- Resolve §2 parameters on coupon rev A → record per §7.
- `T_plate` + screw length: confirm worst-case intrusion < 6.00.
- `C_wire`: needs the encoder connector + wire bundle in hand to set the bend radius.
- After FIT_VERIFIED: promote the coupon geometry to the structural cradle, then into bottom-plate integration (the deck-Z chain).

*Face locates, saddle supports, rear stays open. The parts are measured; the clearances are earned on the printer, not guessed.*

*Cycle: Claude draft → Q audit (10 constraints folded) → Darrell ratify → commit.*

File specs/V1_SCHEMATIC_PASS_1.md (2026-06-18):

# V1_SCHEMATIC_PASS_1

Text-first schematic plan for QD Rover V1. Drives shell layout constraints. **Bench truth before beauty. The shell obeys the schematic.**

---

## 1. Status and non-goals

- **Text schematic only.** Not CAD. Not a final wiring harness.
- **No calibrated thresholds.** Numbers below are part ratings and pack facts, not tuned setpoints.
- **No autonomy.** This plans the body and its safety, not behavior.
- **Not constitutional.** A working pass to be audited, revised, and bench-validated.
- **Purpose:** settle the electrical chain firmly enough to *derive shell zones*, so CAD obeys the schematic rather than the reverse.

Governing rule restated: power is never under-protected to save effort; the shell never dictates where a part goes if safety says otherwise.

---

## 2. System block diagram (text)

```
3S LiPo (Zeee, XT60)
  -> XT60 interconnect
  -> inline blade fuse (rating decision, see section 3)
  -> main rocker switch (SPST)
  -> reverse-polarity protection (ideal-diode/P-FET)
  -> soft-start / inrush block (decision: integral to protector or separate)
  -> PROTECTED RAW BUS  (~11.1V nominal, 12.6V full)
       |
       +-- [optional] hardware load-disconnect guarding the raw bus
       |
       +-- MOTOR RAIL --> E-stop (motor-only cut) --> TB6612FNG VMOT --> motors
       |
       +-- 5V BUCK (Pololu D24V22F5) --> Pi 3 / KB2040 / logic / sensor rails
       |
       +-- BATTERY SENSE --> voltage divider --> ADS1115 (Pi reads pack V)
       |
       +-- LiPo low-voltage ALARM via balance lead (independent, always-on)
       |
       +-- Pi HOLD-UP / UPS path on the 5V rail (graceful shutdown, F14)
```

Key invariant (from power-safety pass): **the E-stop cuts the motor rail, NOT the 5V/Pi rail.** The Pi must stay alive long enough to write its last trace. Motors die instantly; the brain dies gracefully.

---

## 3. Power + safety schematic pass

| Part | Status | Voltage | Current concern | Chain position | Connector/wire | Safety note | Open decision |
|---|---|---|---|---|---|---|---|
| Zeee 3S 2200mAh LiPo | HAVE | 11.1V nom / 12.6V full / ~9.0V empty | ~4A normal, motor stall transients | Source | XT60 (female on pack side) | Bare pack, NO onboard protection; store 3.8V/cell | — |
| XT60 interconnect | HAVE/CONFIRM | pack V | 60A rated, far above draw | Source -> fuse | XT60H solder-cup, fill for 22AWG | Keyed; can't reverse at connector | Q1: count pairs |
| Inline blade fuse + holder | HAVE | pack V | Protects WIRING, not silicon | After XT60 | ~16AWG holder leads, bracket to 22AWG bus | 5A or 7.5A only; never 15A+ (melts small wire) | **Fuse rating: 5A vs 7.5A** |
| Main rocker switch (KCD1) | HAVE | pack V | ~6A rated | After fuse | spade pigtails | Fuse UPSTREAM of switch (correct) | D1: placement (not in CAD) |
| Reverse-polarity protector | ORDERED (Pololu #5387) | 4-60V | 25A continuous (~50A few sec) | After switch, before bus branch | inline, 22AWG+ | Protects whole bus from reversed pack. NON-BLOCKING version: lets motor regen current flow back to the pack as the big sink. Do NOT substitute ideal-diode #5388 (would block regen, push spike onto motor rail). | resolved |
| Soft-start / inrush block | DECIDE/BUY | pack V | limits inrush into buck caps | Same node as reverse protector | inline | Prevents contact pitting / nuisance fuse blow | Integral to protector datasheet, or separate part |
| Protected raw bus | (node) | ~11.1V | sum of all branches | Distribution point | soldered/Perma-Proto | Everything downstream is now protected | — |
| Pololu D24V22F5 buck | HAVE | in 11.1V -> out 5V | 2.5A out; Pi ~0.7-1A + LED band | Bus -> 5V rail | inline, decoupled | Holds 5V across full discharge (no brownout) | 5V rail budget (F13) |
| TB6612FNG driver | HAVE | VMOT to 13.5V (>12.6V OK) | 1.2A cont / 3.2A peak per ch; stall 0.9A OK | Motor rail -> motors | needs PWM x2, dir x4, STBY | STBY pin = a software stop path (distinct from E-stop) | — |
| Motor-only E-stop | DECIDE/BUY | motor rail V | full motor current | Between bus and VMOT | switch/relay rated > stall | Cuts motors, leaves Pi alive | **E-stop part + placement** |
| ADS1115 + divider | HAVE | reads scaled pack V | uA | Bus -> ADC | STEMMA QT / header | Enables software LVC + graceful-shutdown trigger (telemetry, not safety) | divider ratio |
| LiPo low-voltage alarm | ORDERED (Apex #1655, 4 units) | 1-8S | uA | Balance lead | balance connector | Independent always-on scream-box; needs no brain | resolved |
| Hardware load-disconnect | DECIDE->BUY | 3S | > stall current | Guards raw bus | inline discharge path | The REAL hardware LVC; cuts power without the Pi | **Finished-pack inline cutoff - NOT a cell-building BMS** |
| Pi hold-up / UPS | DECIDE->BUY | 5V | holds Pi ~seconds | On 5V rail | board-dependent | Graceful shutdown window (F14) | **Pi-3 mechanical fit-check first** |
| Bulk caps (electrolytic) | HAVE | rail V | absorb spikes | TB6612 VMOT, buck IN, buck OUT, local | soldered close to pins | Designed in, not bolted on after noise appears | verify on Hantek |

**Layered protection summary:** fuse (wire fire) -> reverse protector (polarity) -> soft-start (inrush) -> hardware load-disconnect (over-discharge, brain-independent) -> ADS1115 software LVC (graceful, telemetry) -> balance-lead alarm (audible, independent). Independent layers; no single point carries all the protection.

---

## 4. Compute / control schematic pass

**Pi 3 (HAVE):** main body agent - vision (CSI camera), logging, comms, the I2C sensor bus, ADS1115 pack-sense read, and the graceful-shutdown decision. Powered from the 5V buck on the rover (CanaKit USB supply is bench-only).

**KB2040 / RP2040 (HAVE):** *intended* reflex co-processor - fast body-side signals: encoder quadrature (PIO), WS2812 LED band (PIO, sidesteps F9 PCM collision), and direct dumb/fast reflex sensors (cliff/tilt).

**Pi <-> KB2040 link:** serial (UART) or I2C, KB2040 as a peripheral. Decision deferred, but the *physical* link (a few wires + connector) is reserved now.

**Signal placement:**
- **Lives on Pi day one:** camera (CSI), I2C sensor bus (ToF, IMU, ADS1115, RTC via mux/hub), pack-sense read, logging, comms.
- **Intended to move to KB2040:** encoder counting, WS2812 LED band, sub-100ms reflex inputs (cliff/tilt). *Reason to offload:* non-real-time Pi scheduler makes tight-timing tasks unreliable; the RP2040 PIO does them deterministically.
- **Reserved but NOT day-one required:** the entire KB2040 path. V1 first power-on and bench bring-up can be **Pi-only**.

**Pressure-test - Pi-only vs Pi+KB2040 (explicit, not silent):**
- *Pi-only is sufficient for first bench power-on and early bring-up.* The Pi can read encoders and drive the LED band slowly enough to validate the stack. This is the recommended day-one runtime.
- *Pi-only is NOT sufficient for the final reflex layer.* Sub-100ms hardcoded protection and clean WS2812 timing want the RP2040. Asking the Pi to do them long-term re-introduces F9 (PCM/LED collision) and timing jitter.
- **Therefore (CONFIRMED):** reserve KB2040 *physical space and connectors now*; run **Pi-only day one**; intend **Pi+KB2040 for the final reflex architecture**. "Physical layout reserved" != "runtime required." This is the split the prompt asked for, stated openly and now decided: build the body to accept the co-processor, bring up the brain without it, add it when the reflex code is ready.

**Serial / debug:** FT232RL USB-serial console into Pi UART (GPIO14/15) for headless bring-up - **jumper to 3.3V, Pi UART is not 5V-tolerant.** Zero network dependency.

**SD corruption / F14:** read-only rootfs and/or graceful shutdown triggered by ADS1115 pack-sense, backed by the Pi hold-up cap so the OS lands cleanly before power is gone. The SD module/logging-shield in inventory does NOT fix this (different bus) - it's a filesystem + power-timing fix.

---

## 5. Drive + encoder schematic pass

- **TB6612FNG (HAVE):** VMOT from motor rail (post-E-stop). Logic from 3.3V. Needs from controller: PWMA, PWMB, AIN1/AIN2, BIN1/BIN2, STBY. STBY is a software-disable distinct from the hardware E-stop.
- **Motors (HAVE):** 2x Pololu 25D 47:1 with 48 CPR encoders. Stall 0.9A (within TB6612). 4mm D-shaft.
- **Motor power path:** raw bus -> E-stop -> VMOT. Motor power NEVER routed through breadboard or logic rail.
- **Encoder power:** encoder Vcc 3.5-20V; outputs swing to Vcc. Run encoders at 5V.
- **BSS138 level shifter (HAVE):** 4-ch - 2 encoders x A/B. Encoder 5V outputs -> BSS138 -> 3.3V Pi/KB2040 GPIO. Resolves F1 (5V into Pi pin = damage).
- **Encoder A/B signals:** quadrature. **Day one:** Pi can read them (validation). **Intended:** KB2040 PIO counts them (deterministic, frees the Pi). Reserve the routing so either consumer works.
- **Motor noise / decoupling:** bulk cap at VMOT; keep motor wiring away from sensor bus; verify rail noise on the Hantek before trusting sensor readings during motion.

---

## 6. Sensor bus schematic pass

**Canonical V1 sensor set (locked):** camera, forward ToF, downward floor/cliff sensing, IMU, encoders, and battery voltage sense. Encoders (proprioception) and battery voltage sense (interoception) are first-class senses, not just drivetrain/power parts — she feels her own motion and her own energy state. Nothing beyond this list ships in V1 (F8).

- **Pi Global Shutter Camera (HAVE):** CSI ribbon (15-pin, 24in flex) -> Pi. Global shutter deliberate (moving robot, no rolling-shutter jello). Fragile flex - route, don't pinch.
- **VL53L4CD ToF x2 (HAVE):** both fixed addr 0x29 -> MUST sit on separate PCA9548 mux channels. Ridge-mounted, flank camera (forward distance).
- **Downward floor/cliff sensing (REQUIRED — RESOLVED):** V1 MUST have downward sensing for cliff/edge detection before any rolling movement. **Resolved to 2x VL53L4CD downward ToF (Pololu #3692, ORDERED)** — front-left + front-right underside, each on its own PCA9548 mux channel (same address-collision handling as the forward ToF; all VL53 default to 0x29). VL53L4CD ToF reduces dependence on surface reflectance compared with simple IR reflectance sensors, but tile/carpet/drop-off behavior must still be bench-validated. A 6-inch drop should read as a clean distance jump (to be confirmed on the bench). The 37-in-1 IR reflectance part is now **bench-only backup, NOT trusted V1 fall protection** (surface-dependent). Ultra-low-power interrupt mode (<100uA) suits a reflex "is the floor still there" trigger. Build-blocking requirement now satisfied by ordered hardware.
- **PCA9548 mux x2 (HAVE):** resolves ToF collision; also isolates any other 0x68/0x29 colliders.
- **Qwiic/STEMMA 5-port hub (HAVE):** fan-out for unique-address devices (use hub for unique addrs, mux for colliders).
- **BNO085 IMU (HAVE):** tilt/tip detection (F2). **Known I2C clock-stretch trouble on Pi -> run UART-RVC or SPI**, or budget I2C bring-up time. Do not assume plain I2C works.
- **ADS1115 (HAVE):** pack-sense + any analog. Addr strappable.
- **DS3231 RTC (HAVE):** timestamps significance/decay. Fixed 0x68 - a 2nd RTC cannot share the bus (F12); one per bus or mux it.
- **I2C address map:** every device assigned to hub port or mux channel; colliders (2x ToF, 2nd RTC) explicitly separated. Build the address map before wiring.
- **Body-to-ridge connector:** locked 6-wire JST-XH (sensor signals only - **no servo PWM across the ridge joint**, per F6). JST-XH chosen over tiny JST-SH for the moving/flex joint (robust). Mux-in-ridge could collapse the run toward 4-wire I2C - open (D6).

---

## 7. Safety / reflex event contract

No final numeric thresholds. Each event tagged by where it lives.

| Event | Implementation | Notes |
|---|---|---|
| E-stop (motor cut) | **Hardware only** | Cuts motor rail; Pi stays alive |
| Lost link | Pi software (-> KB2040 later) | Comms watchdog -> safe stop |
| Tilt threshold | Pi software now; **KB2040 intended** | From BNO085; reflex-grade later |
| Floor absence / cliff | **2x VL53L4CD downward ToF (ORDERED)**; Pi-readable day one, KB2040-reflex later | Build-blocking requirement now met by hardware; 37-in-1 IR is bench backup only |
| Low voltage | Layered: hardware load-disconnect + Pi software (ADS1115) + balance alarm | Hardware is the real cutoff; software is graceful; alarm is audible |
| Motor command timeout | Pi software now; **KB2040 intended** | Dead-man on motion commands |
| Motor rail fault | Hardware (fuse) + future refinement | Over-current -> fuse; finer sensing later |
| Pi shutdown in progress | Pi software + hold-up cap | Hold-up buys the graceful window (F14) |

Reflex layer (sub-100ms) is *intended* for KB2040; day one these run on the Pi at coarser timing for validation only - explicitly not the final safety implementation.

---

## 8. Shell layout constraints derived from schematic (zones only, NOT a design)

- **Low center battery zone** - pack low and centered (CG, F2); the heaviest mass sets the rover's stability.
- **Rear / service access** - XT60, fuse holder, main switch reachable without disassembly (F4: switch placement still open).
- **Pi / service hatch** - top-shell hatch for Pi, SD access, and a heat path (F15: Pi 3 runs warm; needs airflow/vent).
- **Power distribution zone** - protected-bus node, buck, caps, reverse/inrush block grouped; short fat power runs.
- **Motor / wheel zones** - 2 drive wheels + caster; caster shim height vs axle for a level deck (F2). Wheel size vs 72mm body open (D2).
- **Front lower floor-sensor zone (CLIFF BAY — concrete):** a two-port downward-ToF cliff bay. Two VL53L4CD sensors at **front-left + front-right underside**, each with a **clear downward optical port** (small opening or IR-transparent window — ToF cannot range through opaque shell). **Rigid, fixed-height mounting** (a wobbling sensor gives noisy distance; the fixed bay height sets the floor-distance baseline against which a drop reads as a sudden increase). **Recessed/protected** so the sensors don't scrape on lips or carpet. **Serviceable STEMMA/Qwiic wiring path** from each ToF to the PCA9548 mux. Sensors sit near the leading edge so QD sees the drop before a wheel crosses it.
- **Front ridge zone** - camera centered, ToF flanking; ridge is directional, not a face.
- **Body-to-ridge cable path** - protected route for the 6-wire JST-XH (and flex-rated for v1.5 articulation).
- **E-stop physical access** - reachable, unambiguous; cuts motors only.
- **Ventilation** - vent path tied to the Pi heat zone.
- **Removable panels + strain relief** - every connector serviceable; wires strain-relieved; **no cramped stacking** (the schematic must fit with room to work).

---

## 9. Open decisions before CAD (ranked by build-blocking priority)

1. **Compute topology - CONFIRMED (D3).** Reserve KB2040 space + connectors; run Pi-only day one; intend Pi+KB2040 for the final reflex architecture. Decided. (Remaining layout work: route encoder/reflex signals so either consumer works.)
2. **Downward floor/cliff sensor - RESOLVED.** 2x VL53L4CD downward ToF ordered (Pololu #3692). Remaining: define the two-port cliff bay geometry in CAD (see section 8).
3. **Hardware load-disconnect - finished-pack inline cutoff.** Pin the exact part (NOT a cell-building BMS). Shapes the protected-bus node.
4. **Fuse rating - 5A vs 7.5A.** Quick but real; sizes the protection.
5. **E-stop part + placement.** Motor-only cut; needs a physical home.
6. **Reverse-protection part - RESOLVED.** Pololu #5387 non-blocking 25A ordered (NOT ideal-diode #5388).
7. **Inrush / soft-start handling.** Integral to the protector, or a separate block.
8. **Pi hold-up / UPS candidate.** After Pi-3 mechanical fit-check.
9. **Body-to-ridge connector / topology (D6).** 6-wire JST-XH confirmed vs mux-in-ridge 4-wire.
10. **Pi mounting height / standoff method (D4).** M2.5 vs M3 reconciliation (F7).
11. **Battery placement / CG (F2).**
12. **Caster shim / wheel geometry (D2, F2).**

---

## 10. First bench tests driven by schematic (in order)

1. **Continuity / polarity** - DMM every power node before any power applied.
2. **Current-limited raw bus** - Tacklife bench supply (CC limit) standing in for the pack; never the LiPo first.
3. **Buck 5V validation with NO Pi** - confirm clean 5V before anything sensitive is connected.
4. **Pi power-up from buck** - Pi boots on rover power.
5. **Motor rail disabled** - verify motors stay dead with E-stop open / STBY low.
6. **E-stop motor cut with Pi alive** - trip E-stop; motors die, Pi keeps running (the core invariant).
7. **ADS1115 pack sense** - read scaled pack V; sanity-check against DMM.
8. **TB6612 dry spin on blocks** - wheels off the ground, low PWM.
9. **Encoder read through BSS138** - confirm A/B quadrature at 3.3V.
10. **Sensor bus scan** - I2C scan; confirm address map, mux channels, no collisions; bring up BNO085 in its non-I2C mode if needed.
11. **Floor / cliff sensor bench test** - validate downward sensing **before any rolling movement**.

Rolling movement is the *last* thing, only after cliff sensing works.

---

## 11. What NOT to buy / NOT to build yet

- No LiDAR. No GPS. No arm. No suspension. No second camera. No sensor flood - V1 sensing is the locked canonical set only (camera, forward ToF, downward cliff, IMU, encoders, battery voltage sense), nothing more (F8).
- No final shell before section 8 zones are settled and bench-validated.
- No autonomy.
- No word-claims - no "safe," "clear," "path." The forbidden-claims discipline applies here too.
- No cell-building 3S BMS / "60A lithium board" for the load-disconnect.

---

## 12. Final recommendation

- **V1 schematic pass ready for Q audit:** YES. The chain is complete, layered, and inventory-true; every part is placed; the Pi-only-vs-KB2040 split is explicit, not silent.
- **Darrell can start buying the small power/safety parts:** YES for the unambiguous ones - LiPo alarm buzzer (x2-3), reverse-polarity protector (pin the exact Pololu part), heat gun if not owned. HOLD on the load-disconnect, Pi hold-up, and inrush part until their decisions (section 9 #3, #7, #8) are pinned - those are "decide then buy," not guesses.
- **Shell constraints ready to hand to CAD:** ZONES yes (section 8), final geometry no. CAD may lay out zones; it may not finalize until the downward-sensor zone is settled.
- **Single next decision:** **downward floor/cliff sensor — confirm-or-replace the candidate part and define its front-lower mounting zone.** With compute topology now confirmed (reserve KB2040, Pi-only day one), the cliff sensor is the top remaining build-blocker: she cannot safely roll until she can see an edge. Settle it and the front-lower shell zone unlocks.

**Truth over comfort. Bench truth before beauty. The shell obeys the schematic.**

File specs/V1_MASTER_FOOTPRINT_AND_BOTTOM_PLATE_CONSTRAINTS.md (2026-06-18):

# V1_MASTER_FOOTPRINT_AND_BOTTOM_PLATE_CONSTRAINTS

> **v1.2 amendment (this revision).** This revision demotes the body envelope from locked constraint to **provisional target**, **kills the 72 mm shell cap** (replaced by a derived height ≈90 mm, A1.1), **locks the motor mount as a printed cradle** (B6 #12 closed), and adds the **governing design hierarchy**. It supersedes v1.1 on every point of conflict and preserves everything else byte-for-byte. Items tagged **(v1.2)**. Decided by Darrell + Q (hierarchy + provisional-envelope language) and Claude (height derivation); ratified by Darrell.
>
> **v1.1 amendment.** This amendment sharpens `60810ce`. It does not replace it. The datum, axis convention, envelope, wheel truth, lookahead rule, and cliff-bay architecture locked in `60810ce` are unchanged. v1.1 adds one datum, reservations and held items, a safety non-claim, one promoted OPEN DECISION, and several gated measurements. Every new or reclassified item is tagged **(v1.1)** so the diff against `60810ce` is legible. Audited by Q, ratified by Darrell.

The shared datum every shell module references. **The wheel chooses the floor relationship; the floor relationship chooses the sensor geometry; the sensor geometry chooses the front underside. Only then does the pill become honest.** (Q)

**Status:** constraints pass, not CAD. Defines the footprint, the datums, and the bottom-plate zones — the parent both the bottom plate and the outer profile hang off. Not final geometry; the numbers that ARE locked are marked LOCKED, the ones still open are marked OPEN.

**Build order (ratified):** master footprint (this doc, Part A) -> bottom plate (Part B) -> core frame -> top shell -> swappable front module. Pretty shell never leads.

---

## Governing design hierarchy (v1.2)

Ratified order of precedence. Every dimension and every fork in this doc is judged against this list, top down:
1. **Meets physics and safety requirements.**
2. **Easy to work on.**
3. **Easy to assemble.**
4. **Easy to access and service.**
5. **Durable enough for staged testing.**
6. **Looks good — only after 1-5 survive.**

**Provisional-envelope rule (Q):** *All body dimensions are provisional envelope targets until validated against physics, serviceability, wiring clearance, thermal behavior, and assembly access. If those requirements conflict with the aesthetic envelope, the envelope yields.*

**Receipt rule (v1.2):** when the envelope yields, the doc records *what it yielded to and by how much* (e.g. "height 72 -> ~90 mm to seat the Pi stack above the deck"). Provisional never means untracked. Every grown dimension carries its reason, so no number is ever again inherited without a source.

**Design rule:** compact where possible, accessible where necessary, safe always, pretty last. Draw ugly if ugly tells the truth.

## Settled inputs this doc is built on

| Decision | Value | Source |
|---|---|---|
| D2 wheels | **Pololu 80mm**, protrude through side cutouts | Darrell ratified (function over form; keyed hub keeps encoders honest) |
| Envelope status **(v1.2)** | **Provisional targets, not constraints.** 180 x 200 = footprint targets; height is **derived ~90 mm** (was 72 — killed, see A1.1). Envelope yields to physics/serviceability. | Darrell hierarchy + Q provisional rule |
| Motor mount **(v1.2)** | **Printed cradle** (Pololu #2676 bracket not in BOM; cradle prints in-house, tunable standoff, integrates encoder/wire/hub). | Darrell ratified |
| Derived height **(v1.2)** | Deck top **~57 mm**, ground clearance **27.5 mm**, shell **~90 mm** (soft above deck pending Pi-stack + shell-thickness measure). | Claude derivation |
| V1 crawl speed | **0.05 - 0.10 m/s** (assumption baked into safety geometry) | Q |
| Cliff lookahead | sensor detection point **>= 50 mm ahead of wheel commitment** | Q (closes Claude falsifier #1) |
| Cliff bay | **3 pockets; L + R populated, center reserved/blanked** | Q + Claude (closes falsifier #2) |
| Cliff sensor | 2x VL53L4CD downward ToF, 18deg cone, on PCA9548 mux | ORDERED (Pololu #3692) |
| Caster | single ball caster, **rear underside** | Q |
| CG | heaviest mass (battery) low + centered | F2 |

---

## PART A — Master footprint and datums

### A1. The envelope
- Body: **180 mm wide x 200 mm long**, tapered pill. **Height is derived, not capped (v1.2)** — see the Z-stack in A1.1; the old 72 mm figure is dead.
- Orientation convention (LOCKED, Q-confirmed against chassis lock — NOT flipped): **+X = forward** (direction of travel / nose), **+Y = left**, **+Z = up**. Origin at `DRIVE_AXLE_FLOOR_DATUM` (A2).
- **Axis assignment (convention LOCKED; magnitudes provisional, v1.2):** travel / fore-aft = **X** (target 200 mm); width = **Y** (target 180 mm); vertical = **Z** (**derived ~90 mm shell height — the 72 mm cap is killed; see A1.1**). The axis *convention* is locked; the *magnitudes* are provisional envelope targets that yield to physics/serviceability per the hierarchy.
- **Axis ranges:** X roughly -rear to +front across ~200 mm; Y roughly -90 mm to +90 mm across ~180 mm; Z floor upward to **~90 mm derived shell height**. The **80 mm wheels protrude through the side cutouts** as real-envelope truth.
- Wheels protrude past the 180 mm width through side cutouts. The **real envelope** including wheels is wider than 180 mm — CAD must reserve clearance for the bulge so the side cutouts don't fight the outer profile. **(v1.2)** With the shell now at ~90 mm, the wheel top (80 mm) sits **below** the shell top — wheels no longer stand proud of the **top**, only past the **sides**. The old "wheels exceed shell height" note was a 72 mm artifact and is retired.

### A1.1 Derived height — the Z-stack (v1.2)
The 72 mm cap was an inherited number with no first-principles owner. Tested against the build it proved an **under-spec** — it could not seat a Pi above the deck in the serviceable motor-under-solid-deck topology. Per the hierarchy, the envelope yielded and height is now **derived bottom-up from the floor**:

| Z (mm) | Plane | Status |
|---|---|---|
| 0 | floor / datum | LOCKED |
| 27.5 | motor belly (lowest point) -> **ground clearance 27.5 mm** | derived (Ø25 motor on axle) |
| 40 | drive axle | LOCKED (wheel radius) |
| 52.5 | motor top | derived |
| ~57 | **deck top — solid plate** | derived (motor top + cradle wall + ~4 mm plate) |
| 57 -> ~87 | cabin: Pi 3 stack + wire bend radius + thermal gap (~30 mm) | **soft** — pending measure |
| ~90 | **derived shell top** | **soft** — firms on the two measures below |
| >90 | ridge reach reserved (v1.5 camera tilt) | reserved |

**Two measured inputs firm ~90 into exact:** (1) Pi 3 stack height as installed (standoffs + board + tallest component / any HAT); (2) chosen top-shell wall thickness. Everything from the deck **down** (0 -> 57) is already hard off the motor + cradle geometry. The new provisional cap = this derived minimum + margin, and it carries its receipt (A1.1) instead of being inherited.

### A2. The master datum (origin) — `DRIVE_AXLE_FLOOR_DATUM`
- **Datum name: `DRIVE_AXLE_FLOOR_DATUM`** (Q-required naming). NOT "center datum" — that would be confusable with the geometric center of the pill, which this is NOT. The datum is where motion meets the floor, not the centroid of the shell.
- **Datum = the floor-contact plane, centered between the two drive wheels, on the travel centerline.**
- Why here, not a corner or the pill center: the two things that must stay true relative to each other are the **wheels** (they set the floor relationship / motion-commitment reference) and the **cliff sensors** (they must lead the wheels by >=50mm). The caster is the rear stability reference; battery CG is measured relative to the support triangle. Anchoring the origin at the wheel axle centerline on the centerline makes both the wheelbase and the lookahead measurable as simple +X/-X offsets from one known point. (Q: "The datum is not the shell. The datum is where motion meets the floor. Start there.")
- Every other feature (battery well, cliff bay, caster, power zone) is dimensioned as an offset from `DRIVE_AXLE_FLOOR_DATUM`. Move the datum, everything re-references cleanly.

### A3. The wheel line (sets the floor relationship)
- Two drive wheels, 80mm dia, on a common axle line perpendicular to travel.
- **Wheelbase axis = the master datum Y-axis** (the wheels straddle the origin, one at +Y, one at -Y).
- Wheel track (center-to-center across the body): OPEN — set by motor mount width + wheel hub width; must keep the 80mm wheels clearing the internal frame while protruding through the side cutouts. CAD sizes this first because it sets how far the cutouts sit.
- Deck height above floor = wheel radius (40mm) minus how much axle sits below deck — drives the caster shim (A5). **(v1.1)** The "how much axle sits below deck" term is NOT pure arithmetic — it is set by the **motor-mount method**. **(v1.2) RESOLVED:** motor mount = **printed cradle** (B6 #12 closed). The cradle seats the motor under a solid, uncut plate (serviceability-first per the hierarchy), giving **deck top ~57 mm** (motor top 52.5 + cradle wall + ~4 mm plate) and **ground clearance 27.5 mm** at the motor belly. Deck Z is now hard, and the caster shim (A5) is computable.

### A4. The cliff-lookahead constraint (safety geometry — V1-conditional, non-negotiable within its regime)
- The downward cliff sensors sit FORWARD of the wheels by a distance set by stopping distance.
- **Constraint (Q-phrased, exact):** *At V1 crawl speed <= 0.10 m/s, the downward ToF detection point must sit at least 50 mm ahead of the drive-wheel commitment/contact line. Any speed increase above 0.10 m/s invalidates this allowance and requires recomputation AND bench validation before use.*
- This is a **minimum initial V1 rule, not a universal truth** — the 50 mm is valid only in the <=0.10 m/s regime. It is a footprint constraint, not a styling choice: it sets the **minimum forward offset of the cliff bay from the wheel line**. If the body isn't long enough forward to give 50 mm clean lookahead, either the bay moves forward (into the nose) or the speed cap drops.
- Re-check trigger baked in: any later speed above 0.10 m/s does not just need a new number — it needs **recompute + bench validation** before that speed is allowed. A future "let's go faster" cannot silently break cliff safety.
- **(v1.1)** The forward X offset is necessary but NOT sufficient for cliff reliability. The sensor's vertical geometry (Z baseline height, optical-port recess, lip clearance) also gates whether the reading is true — see B3 and the cone-clearance interface rule in A7.

### A5. The caster (rear) and deck level
- Single ball caster, rear underside, on the travel centerline behind the wheel line.
- Rear placement is deliberate: it puts the cliff sensors + wheels forward, so the sensors get the earliest view of a drop before the wheels commit (the geometry enforces "look before you leap").
- Caster height must match the wheel-defined deck height so the deck sits **level** (F2). Caster shim = (wheel-set deck height) - (caster natural height). **(v1.1)** gated by the motor-mount decision. **(v1.2) RESOLVED enough to compute:** deck top is now ~57 mm (A3, cradle locked), and the #2692 caster uses a **1″ (25.4 mm) ball**. The shim holds the rear contact at the deck plane so she sits level; exact shim = (rear deck-to-floor geometry) − (caster natural height incl. the 25.4 mm ball) — a clean measure at the rear layout, no longer a blocked fork.
- A non-level deck tilts every sensor reference, including the cliff baseline — so this is a safety-adjacent dimension, not just cosmetics.

### A6. Center of gravity
- Battery (2200mAh 3S, heaviest single mass) sits **low and centered** over/just behind the master datum, to keep CG between the wheels and low.
- Watch: the cliff bay + swappable front module add mass FORWARD of the wheel line. If that forward mass is enough to lighten the rear caster (reducing traction/stability), shift the battery slightly rearward to compensate. OPEN — resolve once module masses are estimated; flag for a tip/stability check at bench.

### A7. Front-module interface datum — `FRONT_MODULE_INTERFACE_DATUM` **(v1.1)**
- **New datum:** the mating plane between the permanent chassis/bottom plate and the swappable front module (nose). Named `FRONT_MODULE_INTERFACE_DATUM`, dimensioned as an offset from `DRIVE_AXLE_FLOOR_DATUM`.
- Why it must be a datum, not just a description: the cliff sensors are chassis-owned (B2), but their **optical windows pass through the swappable nose**. If the nose's mating plane and window geometry aren't datum-locked, every nose swap risks shifting the windows relative to the fixed sensors.
- **Standing cone-clearance interface rule (safety, plate-owned / nose-honored):** every front module that mounts to this datum MUST guarantee the downward ToF 18deg cone passes **unclipped** — i.e., the optical-port aperture, recess depth, and lip overhang must clear the cone at the sensor's fixed mount height. This is a *permanent constraint on the interface*, not a one-time number: any future nose that violates it makes the sensor lie (reads the tunnel wall, not the floor) even though the chassis-side mount never moved. This is what makes B2's "swap the nose without recalibrating the safety skeleton" actually true.
- Consequence for CAD: the cone-clearance envelope is owned by this datum (plate side); the specific recess depth / lip angle of the *v1 nose* is a COMPUTE number sized against this rule (B3, B6).

### A8. What Part A hands to Part B
The bottom plate (Part B) inherits, as fixed references:
- the master datum (A2)
- the wheel line + track (A3)
- the cliff bay forward offset (A4, the >=50mm rule)
- the caster position + shim target (A5)
- the battery well center (A6)
- **(v1.1)** the front-module interface datum + cone-clearance rule (A7)

---

## PART B — Bottom-plate layout constraints

The bottom plate is the **rigid safety datum**: the part that carries the calibration-critical sensor mounts and never gets swapped. The swappable nose only borrows windows from it.

### B1. Underside zone map (plan view, front to rear)
- **Front underside — CLIFF BAY:** 3 sensor pockets across the width. Populate front-left + front-right now; center pocket molded/printed but **blanked** (reserved). Each pocket: downward optical port, rigid fixed-height mount, recessed so the sensor face doesn't scrape carpet/lips. Sits at the A4 forward offset (>=50mm lead on the wheels).
- **Middle-low — BATTERY WELL:** low, centered, over/just behind the datum (A6). Lowest practical Z for CG. Retains the pack against motion (it can't shift in a turn or it moves CG).
- **Mid-rear L/R — MOTOR / WHEEL MOUNTS:** the two drive motors, axle on the wheel line (A3), wheels exiting through side cutouts. Motor mounts are the most force-bearing feature on the plate — they take drive torque and impact loads.
- **Rear underside — CASTER:** ball caster on centerline, shimmed to deck level (A5).
- **Power-distribution zone (rear-biased, above/beside battery):** protected-bus node, buck, caps, reverse protector #5387, grouped for short fat power runs. Rear service access (F4) for XT60 / fuse / main switch reachable without teardown. **(v1.1)** Space-reserve the **ADS1115 pack-sense** here, near the voltage divider, deliberately routed AWAY from the noisy motor wiring (motor-current noise on the sense lines corrupts pack voltage reads).

### B2. The cliff bay is a bottom-plate feature with front-module windows (LOCKED architecture)
- **Sensor mounts** belong to the bottom plate / chassis datum: rigid, fixed-height, calibration-critical.
- **Optical openings** pass through the swappable front module: the nose has windows that line up over the sensors.
- Consequence: **swap the nose without recalibrating the safety skeleton.** Safety geometry never moves when Darrell restyles the face. **(v1.1)** This promise is only real if every nose honors the cone-clearance interface rule (A7) — a nose with a bad window recess can poison the reading without touching the mount.
- Mount stiffness requirement: a wobbling sensor gives noisy distance; the bay height sets the floor-distance baseline (a drop reads as a sudden increase). Mount must be rigid enough that the baseline doesn't drift with vibration.

### B3. Cliff-pocket geometry constraints
- Each pocket aims its 18deg ToF cone straight down (or slightly toed per bench result).
- Fixed, known mount height above floor = the distance baseline. CAD must hold this height tightly and identically L vs R (mismatched heights = mismatched baselines = false asymmetry).
- Center pocket reserved: if bench testing shows a thin diagonal edge slips through the L/R blind strip, the third sensor drops in with no redesign. No third sensor bought today.
- Wiring: serviceable STEMMA/Qwiic path from each pocket to the PCA9548 mux. Route protected, not pinched by the nose swap.
- **(v1.1) SAFETY NON-CLAIM (Q-required, explicit):** two downward VL53L4CD sensors are **narrow path probes, not full-width front-edge proof.** They protect the left/right wheel-commitment paths only. A drop located in the center blind strip between the L and R cones is **not** guaranteed to be seen at V1. The reserved center pocket exists precisely because full front-edge cliff coverage is **not claimed** until it is bench-tested. CAD and behavior code must not assume edge-to-edge floor sensing.
- **(v1.1) Cliff vertical geometry is a measurable, not a given.** A correct forward X coordinate with a bad recessed tunnel can still make the sensor lie. The following are COMPUTE/MEASURE items (B6), each sized against the cone-clearance rule (A7): downward-ToF floor baseline height, optical-port recess depth, and front-lip clearance angle.
- **(v1.2) Sensor-capability clarifier (Q):** the VL53L4CD ToF **reduces dependence on surface reflectance compared with simple IR reflectance sensors, but tile/carpet/drop-off behavior must still be bench-validated.** No "reflectance solved" claim is made anywhere; real-world edge cases (dark or shiny materials, oblique angles, sensor saturation, recess/tunnel interference) remain live until tested, and are governed by the cone-clearance rule (A7) and the bench-validation triggers (A4, B3).

### B4. Fastener + frame interface (OPEN DECISION — see B6)
- Pi mounts M2.5 (Geekworm), chassis mounts M3 (ruthex) — two fastener systems coexist (F7/D4). Bottom plate uses M3 heat-set inserts for the chassis; Pi standoff method is a Part-C (core frame) concern but the plate must reserve its footprint.
- Bottom-plate-to-core-frame join: **OPEN DECISION (D4)** — not a number. This fork decides serviceability, print orientation, insert style, frame stiffness, and whether top/core lift off without disturbing the safety plate. Plate provides the rigid base; frame stacks on it.

### B5. Service + safety access (from F4)
- XT60, fuse holder, main rocker switch, and the E-stop must be reachable from outside without removing the top shell.
- E-stop physical access: reachable, unambiguous, cuts **motors only** (per schematic Section 7) — the Pi stays alive to write the receipt.
- The power zone groups these at the rear so one service opening reaches them all.

### B6. What stays OPEN after this doc (gates remaining before CAD-final)

Q's check caught a real error in the draft: items filed as arithmetic that are actually design decisions. Corrected split below. **(v1.1)** adds one OPEN DECISION (motor-mount method), gates deck height under it, and adds the wire-channel and cliff-vertical measurables to COMPUTE. **(v1.2)** closes #12 (motor mount = printed cradle) and resolves deck height in #2; the OPEN DECISIONS still standing are **D4 fastener (#9), fuse rating (#10), and E-stop (#11)**.

**OPEN COMPUTE — pure numbers, derivable from chosen/measured parts or first prints:**
1. Wheel track width (A3) — sets cutout position.
2. Deck height + caster shim (A5). **(v1.2) DECK HEIGHT RESOLVED -> deck top ~57 mm** (cradle locked, #12 closed; corrects v1.1's stray "#8" reference). Caster shim remains a measure at the rear layout, now computable against the 25.4 mm caster ball.
3. Exact cliff-bay forward offset in mm (A4) — needs the stopping-distance calc at 0.10 m/s to convert ">=50 mm lead" into a plate coordinate.
4. Battery fore/aft trim for CG (A6) — needs module mass estimates.
5. **(v1.1)** Wire-channel dimensions — minimum channel width/depth, bend radius, strain-relief clearance, and connector service slack (cliff bay -> mux -> core).
6. **(v1.1)** Downward-ToF floor baseline height (sensor Z above floor) — the distance baseline; sized against the cone-clearance rule (A7).
7. **(v1.1)** Optical-port recess depth (v1 nose) — sized so the 18deg cone clears unclipped.
8. **(v1.1)** Front-lip clearance angle (v1 nose) — sized so the lip overhang does not intrude on the cone.

**OPEN DECISION — design forks, NOT arithmetic (must be decided, not measured):**
9. **OPEN DECISION — D4 fastener / interface method.** Not a number. Decides serviceability, print orientation, insert style, frame stiffness, and whether the top/core can come off **without disturbing the safety plate**. A real fork with safety consequences.
10. **OPEN DECISION — fuse rating.** Not placement. An electrical-safety decision tied to wire gauge, stall current, transient tolerance, and nuisance-trip risk.
11. **OPEN DECISION — E-stop actuator type and placement.** Not geometry. A human-access safety decision: reachable, unambiguous, fast under stress.
12. **(v1.2) RESOLVED — motor mount = printed cradle.** (Was OPEN DECISION in v1.1.) The Pololu #2676 bracket is **not in the BOM** — packing slip 1J584435 confirms the order: 2× #4885 gearmotors, #3690 wheels, #713 driver, #2858 buck, #2692 caster — no bracket. Cradle chosen on the hierarchy: prints in-house this weekend (no buy/lead time), tunable standoff, and integrates encoder clearance + wire exit + keyed-hub alignment in one part; the motor drops out **below a solid, uncut plate** (serviceability-first). Trade-off owned explicitly: in-house stiffness/tolerance instead of the bracket's metal precision. Closing this fork closed the whole deck-Z chain: cradle -> deck top ~57 -> ground clearance 27.5 + caster shim (A5) -> derived shell ~90 (A1.1).

### B7. Held items & space reservations (not buys yet, but they claim volume now) **(v1.1)**
These are not populated in V1 and are not open gates before CAD-final, but they affect volume and routing, so CAD must reserve for them now rather than discover them later.
- **KB2040 / RP2040 reflex MCU — SPACE RESERVE / HELD ARCHITECTURE.** Reserve: physical board footprint, 5V/3.3V/GND access, Pi<->KB2040 link path, encoder/reflex/LED routing corridor, and service access. **Reserved for the intended reflex layer — NOT a day-one runtime requirement.** Pi 3 is the day-one brain; the KB2040 path exists so the reflex layer can drop in later without a chassis redesign.
- **Hardware load-disconnect — HELD POWER SAFETY / SPACE RESERVE.** Not selected or bought; reserve power-routing volume so it can be inserted on the motor rail later without re-routing the bus.
- **Pi hold-up / UPS — HELD POWER SAFETY / SPACE RESERVE.** Not selected or bought; reserve volume + a power tap so the Pi can be kept alive across a motor-rail cut (it must survive to write the receipt, B5).

---

## Commit conditions (Q-required — this doc self-certifies)

This artifact is committable because it states:
1. Datum is **`DRIVE_AXLE_FLOOR_DATUM`** (floor-contact plane, between drive wheels, on travel centerline) — not the shell center.
2. **(v1.2 revised)** Axis *convention* locked (X = fore-aft, Y = width, Z = vertical, not flipped); *magnitudes provisional*: 200/180 are footprint targets, and **Z = derived ~90 mm shell height — the 72 mm cap is killed** (it was an under-spec, not a constraint; receipt in A1.1).
3. **80 mm wheels are V1-locked and protrude through side cutouts** as real-envelope truth.
4. **Cliff lookahead >= 50 mm at <= 0.10 m/s**; above that speed → recompute + bench validation.
5. **Left/right downward ToF installed, center pocket reserved.**
6. **Fuse rating and E-stop placement are OPEN DECISIONS**, not mere arithmetic; **D4 fastener** still open. **(v1.2)** motor mount is now CLOSED (printed cradle).
7. **(v1.1)** This amendment **sharpens `60810ce`; it does not replace it.** No locked truth was moved. Added: `FRONT_MODULE_INTERFACE_DATUM` + cone-clearance rule; the explicit two-ToF safety non-claim; motor-mount method as an OPEN DECISION (with deck height gated under it); wire-channel and cliff-vertical measurables in COMPUTE; KB2040 / load-disconnect / Pi-UPS as held / space-reserve.
8. **(v1.2)** The body envelope is **provisional**, governed by the design hierarchy (physics/safety → work-on → assemble → service → durable → pretty-last). The envelope yields to physics/serviceability and records what it yielded to (receipt rule). Concrete results this revision: **72 mm cap killed**, height **derived ~90 mm** (A1.1), motor mount = **printed cradle**, **deck top ~57 mm**, **ground clearance 27.5 mm**. The ~90 is soft above the deck until the Pi-stack height and shell-wall thickness are measured.
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

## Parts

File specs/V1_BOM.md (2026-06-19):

# QD V1 — Bill of Materials & Build-Completion Spec

**Purpose:** the single source of truth for what V1 *requires*, what is *in hand*, what must be *bought*, and what must be *decided* before the build is buyable in one trip. Cross-checked against the full inventory (93 rows) and flags roadmap (30 entries).

**Status:** working spec, not constitutional. Buy list is actionable; decisions block final order on a few items.

**Headline:** V1 is mostly *already bought*. The new-purchase list is short. The bigger risk is unmade **decisions** that gate the build, not missing parts.

---

## How to read this

Every line is tagged:
- **HAVE** — in hand, confirmed, allocated to V1.
- **BUY** — not owned (or not the right part); must order.
- **DECIDE** — a choice gates this; may or may not cost money.
- **CONFIRM** — owned but a count/spec/model is unverified; check before trusting.

---

## 1. Power & Safety

| Item | Status | Note |
|---|---|---|
| 3S 2200mAh LiPo (Zeee, XT60) ×2 | HAVE | 1 run + 1 swap. Store at 3.8V/cell. |
| Buck D24V22F5 5V 2.5A | HAVE | Holds 5V across full discharge. |
| Blade fuse 5–7.5A + inline holder | HAVE | Fuse upstream of switch (correct order). |
| XT60H connectors | HAVE / CONFIRM | Count from photo unconfirmed (Q1). Count the bag. |
| SPST rocker switch (KCD1) | HAVE | But placement not in CAD — see DECIDE D1. |
| SKYRC iMAX B6AC charger | HAVE | Bench. Storage mode habit. |
| LiPo low-voltage alarm buzzer (1–8S) | HAVE | ×4 in hand (Apex #1655, inv row 99). Independent balance-lead scream-box. |
| Pololu reverse-voltage protector, 4–60V 25A | HAVE | #5387 non-blocking, in hand (inv row 97). After fuse/switch, before bus branch. |
| **Inrush / soft-start** | **DECIDE/BUY** | Name as its own schematic block. Confirm whether the reverse protector's datasheet also covers inrush; if not, add a soft-start part. |
| **Hardware low-voltage LOAD-DISCONNECT (not a pack-building BMS)** | **DECIDE → BUY** | The real safety layer. Must be an inline discharge-path cutoff for a *finished RC pack*, NOT a cell-building 3S BMS. Exact part TBD. **Do not buy a generic "3S BMS / protection / 60A lithium" board.** |
| **Raspberry Pi UPS / 5V hold-up board (Pi 3)** | **DECIDE → BUY** | For graceful shutdown (F14). Buy only after a mechanical fit-check against Pi 3 + chassis. |
| Bulk electrolytic caps (decoupling) | HAVE | Inventory rows 88. Place at TB6612 VMOT, buck input, buck output, + local at sensor/logic. Verify rail noise on Hantek. |
| XT60 charge lead (charger ↔ pack) | CONFIRM / maybe BUY | F5: may not be in charger bundle. If absent, build from spare XT60H. |

**Power chain order (ratified):** XT60 → main fuse → main switch → reverse protection → inrush/soft-start → protected raw bus → {motor rail via E-stop→TB6612 VMOT} and {buck→5V→Pi/logic}.

**QD power rule (Q):** E-stop cuts *motor* power; it must NOT instantly kill the Pi. The Pi must stay alive long enough to write its last trace (the "receipt"). Ties the power tree to the Trace Obligation.

---

## 2. Drive

| Item | Status | Note |
|---|---|---|
| Pololu 4885 gearmotors + 48 CPR encoders ×2 | HAVE | Stall 0.9A. |
| TB6612FNG motor driver | HAVE | Survives stall with margin. |
| BSS138 4-ch level converter | HAVE | Resolves F1 (5V enc → 3.3V Pi). Pending wiring. |
| Ball caster | HAVE | 3rd contact point. |
| Wheels | HAVE / DECIDE | Owns Pololu 80mm wheels (3690) BUT locked design called for printed TPU wheels (D2). 80mm > 72mm body (F2). Decide printed-TPU vs bought-wheel before chassis finalize. |

**No drive parts to buy.** One decision (wheels) and one geometry flag (caster shim height vs axle, F2).

---

## 3. Compute & Storage

| Item | Status | Note |
|---|---|---|
| Raspberry Pi 3 | HAVE / CONFIRM | Model B vs B+ unconfirmed (Q5). |
| KB2040 (RP2040) co-processor | HAVE / DECIDE | Reflex Layer-1 + encoder counting + WS2812/I2S offload — or spare. Topology decision D3 (Pi+co-pro vs Pi-only). |
| microSD 32GB (Pi OS) | HAVE | Corruption-on-yank risk → F14 (hold-up + read-only rootfs). |
| Pi heatsinks (from CanaKit) | HAVE | F15: fit them; provide chassis airflow. |
| M2.5 standoff/screw kit (Geekworm) | HAVE / CONFIRM | 1 or 2 boxes? (Q2). Pi=M2.5, chassis=M3 → two fastener systems (F7/D4). |

**No compute parts to buy.** Decisions: compute topology (D3), fastener/mount method (D4), confirm Pi model (Q5).

---

## 4. Sensing — V1 core

| Item | Status | Note |
|---|---|---|
| Pi Global Shutter Camera + 6mm wide lens + 24in flex | HAVE | Core vision. Global shutter is deliberate (motion). |
| VL53L4CD **forward** ToF ×2 (Adafruit #5396) | HAVE | Ridge, flank camera. Both 0x29 → PCA9548 mux (F12). |
| VL53L4CD **downward cliff** ToF ×2 (Pololu #3692) | HAVE | Front-L/R underside, drop detection. Both 0x29 → mux. Received; logging as inv rows 96+. |
| BNO085 IMU | HAVE | Proprioception/tip detect (F2). Use UART-RVC or SPI (F10). 2nd unit = spare or ridge? (Q3). |
| PCA9548 I2C mux ×2 | HAVE | Resolves ToF address collision. |
| DS3231 RTC | HAVE | Timestamps significance. 2nd shares 0x68 → cannot share bus (F12). |
| Qwiic 5-port hub | HAVE | I2C fan-out for unique-address devices. |
| STEMMA QT cables (assorted) | HAVE | Deep stock (rows 19,20,37). |

**No core-sensing parts to buy.** Key call: keep V1 sensing minimal = camera + ToF + IMU (F8 warns against front-loading all ~10 modalities). Everything else → post-V1 plug-in library.

### Reflex-layer sensors (Layer-1, if KB2040 topology chosen — D3)
| Item | Status | Note |
|---|---|---|
| IR reflectance (cliff/edge) | HAVE | From 37-in-1 kit. **Now bench-only backup** — cliff resolved to dedicated VL53L4CD ToF (Pololu #3692); IR is not trusted V1 fall protection (F16). |
| Shock/tilt (impact/tip) | HAVE | From 37-in-1 kit / BNO085. |
| HC-SR501 PIR ×5 | HAVE / DECIDE | At-rest presence only, zero-velocity gated (F17). Array vs spares (Q6). Domes must be exposed → shell openings (F17/D5). |

---

## 5. Chassis, Fasteners & Print

| Item | Status | Note |
|---|---|---|
| Filament: PETG-Tough red, ASA gray, TPU, translucent black PETG | HAVE | Per locked materials. (Verify spool quantities sufficient for 4 modules + spares.) |
| ruthex heat-set inserts (M2/M3/M4/M5) | HAVE | M3 = workhorse. NOTE: no M2.5 → Pi still needs Geekworm M2.5 (F7). |
| M3 socket-head screw kit | HAVE | Chassis standard. |
| Perma-Proto boards ×6 | HAVE | Internal electronics substrate. |
| Hookup wire 22AWG silicone | HAVE | Consider 20/18AWG on pack +lead. |
| JST-XH connector kit | HAVE | Body-to-ridge bus (6-wire locked, F6/D6). |
| Heat-shrink kit | HAVE | Consumable. |
| Heat gun | HAVE | SEEKONE HG350 in hand (inv row 98). Heat-shrink + XT60 solder. (Heat-set inserts use a soldering iron.) |

**No buys here now (heat gun received).** Just confirm filament quantities.

---

## 6. The complete BUY list (one trip)

**Order now — safe, specced:**
*(All three cleared — now in hand, inventory rows 97–99.)*
1. LiPo low-voltage alarm buzzer — ✓ Apex #1655 ×4
2. Reverse-voltage protector — ✓ Pololu #5387 (non-blocking 25A)
3. Heat gun — ✓ SEEKONE HG350

**Order once decided (don't guess the part):**
4. **Hardware low-voltage load-disconnect** — inline discharge cutoff for a finished RC pack (NOT a cell-building BMS). Pin exact part first.
5. **Raspberry Pi 3 UPS / 5V hold-up board** — after mechanical fit-check.
6. **Inrush/soft-start part** — only if the reverse protector's datasheet doesn't already cover inrush.
7. **XT60 charge lead** — only if absent from charger bundle (else build from spares).

**Possibly:** extra filament if spool counts are short for all four modules + calibration + spares.

**Explicitly DO NOT buy:** any generic "3S BMS," "drill-pack protection board," or "60A 3S lithium board" — wrong class for a finished RC pack.

---

## 7. Decisions that gate the build (cost nothing, block progress)

| ID | Decision | Blocks |
|---|---|---|
| D1 | Switch placement (underside/rear vs intentional cue) — F4 | Top-shell print |
| D2 | Wheels: printed TPU vs Pololu 80mm — F2 | Chassis finalize |
| D3 | Compute topology: Pi + KB2040 co-pro vs Pi-only — F11 | Reflex layer, F9 resolution |
| D4 | Fastener/mount method (M2.5 inserts vs nut-capture) + standoff height — F7 | Bottom plate, hatch, cable routing |
| D5 | PIR dome openings in shell (if PIR in V1) — F17 | Shell design |
| D6 | Body-to-ridge bus topology (mux-in-ridge → 4-wire?) + connector — F6 | Ridge wiring |

**Recommended order:** settle D3 (compute topology) first — it cascades into reflex sensors, F9, and wiring. Then D2/D4 (chassis-finalizing). D1/D5/D6 can follow.

---

## 8. Open confirmations (quick checks)

- Q1: XT60H pair count (count the bag)
- Q2: Geekworm standoff kit — 1 or 2 boxes
- Q3: 2nd BNO085 — ridge or spare
- Q5: Pi 3 model B vs B+ (read silkscreen)
- T1: heat gun owned? — **YES** (SEEKONE HG350, inv row 98)
- Filament: enough for all four modules + calibration + spares?

---

## Bottom line

V1's parts are ~95% in hand. The alarm, reverse protector, and heat gun are now **in hand** — the remaining buys are just the 2–4 **decide-then-buy** items (load-disconnect, Pi UPS, inrush, charge lead). The real work before the build is the six **decisions** — none cost money, several block the print. Settle compute topology (D3) first.

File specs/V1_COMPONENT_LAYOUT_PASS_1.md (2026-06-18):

# V1_COMPONENT_LAYOUT_PASS_1

> **Status:** first component-placement pass (nervous-system-first). NOT CAD-final, NOT a shell. A coordinate/zone map referenced off `DRIVE_AXLE_FLOOR_DATUM`, built from the locked footprint (`60810ce` → v1.1 `889c813` → v1.2 `0c8a198`) and the cradle/height decisions ratified this cycle. Drafted by Claude; **Q-audited** (5 fixes + 7 collision checks folded in below); awaiting Darrell ratification → commit.
>
> Tags: **LOCKED** (settled upstream), **PROPOSED** (this pass, defensible but open to ratification), **MEASURE** (needs a caliper number off the in-hand part before CAD), **OPEN DECISION** / **OPEN DESIGN** (a choice, not a number).
>
> **Placement hierarchy (Q-ratified) — every zone is judged against this, top down:** (1) LiPo access + safety; (2) motor/wheel/caster geometry; (3) cliff-sensor geometry; (4) power cutoff/fuse/service corridor; (5) Pi access + heat path; (6) sensor/logic routing; (7) shell protection. *Nervous system first; the skeleton obeys the parts.*

**Frame:** +X forward, +Y left, +Z up. Origin `DRIVE_AXLE_FLOOR_DATUM` = floor-contact plane, centered between drive wheels, on travel centerline. Working body envelope (provisional targets per v1.2): X ∈ [−100, +100] (200 fore-aft), Y ∈ [−90, +90] (180 width), Z ∈ [0, ~90] (derived shell).

**Reference planes (LOCKED / derived this cycle):**
| Z (mm) | Plane |
|---|---|
| 0 | floor / datum |
| 27.5 | motor belly (lowest point) |
| 40 | drive axle |
| 52.5 | motor top |
| ~57 | deck top (solid plate) |
| ~90 | shell top (provisional) |
| 29 | caster mount-to-floor height (MEASURED: #2692 = 29 mm overall) |
| 80 | wheel top (Ø80 wheel, sits below the ~90 shell) |

---

## 1. Required measured dimensions before CAD

CAD cannot finalize until these come off the **actual in-hand parts** (nominals shown are for this pass only):

1. **Pi 3 installed stack height** — standoff + board + tallest component (USB/Ethernet ~16 mm) + any HAT. Nominal ~25 mm. Sets the cabin and confirms ~90 shell. **The single biggest soft number.**
2. **#4885 faceplate** — the two M3 hole spacing + center-boss diameter. Sets the cradle face. Nominal: 25 mm body, boss + 2× M3 on a known small pattern — measure it.
3. **#4885 encoder backshell** — how far the encoder/cap protrudes past the 67 mm and its wire-exit face. Sets inboard motor clearance + wire exit.
4. **Wheel track (Y of faceplate)** — driven by the #3690 collet+hub stack width (how far the wheel seats off the shaft). Sets motor inboard reach and the central gap (§4.1). **OPEN COMPUTE in the footprint doc; this pass needs the collet stack measured.**
5. **Battery pack** — confirm the in-hand Zeee against nominal **75 × 34 × 26.5 mm** (shorty pack, soft case, XT60). Soft-pack swell margin: add ~1–2 mm.
6. **Top-shell wall thickness** (your choice) — closes the ~90 mm derivation.

Already measured/confirmed this cycle: **caster #2692 = 29 mm overall, 1″ ball, 3× M3 base**; motor body Ø25 × 67L, 4 mm D-shaft out 12.5 mm.

---

## 2. Proposed top-down component zones (X/Y ranges, from datum)

Read as a fore-to-aft sequence through the underside, then the cabin above.

**UNDERSIDE / BASEMENT (Z 0–57):**

- **Cliff bay (front).** PROPOSED X **+50 to +85**, set by the ≥50 mm lookahead (LOCKED). Pockets: L at Y +28 to +58, R at Y −28 to −58, **center reserved** Y −14 to +14 (blanked). Sensors VL53L4CD (~17×12), downward, rigid fixed-height mount (chassis-owned).
- **Front-mid (X +12 to +50): KEPT CLEAR.** PROPOSED. The battery is *forbidden* here — see §4.2 (CG/tip-forward). Reserved for wire routing + cliff-bay wiring rise.
- **Wheel line (X −12.5 to +12.5): MOTORS + WHEELS.** LOCKED axle X=0. Motor cylinders span Z 27.5–52.5, reaching inboard from the faceplate (Y ±~75) toward Y ±~8. Wheels Ø80 at the sides through cutouts (Z 0–80).
- **Mid-rear (X −13 to −47): BATTERY.** PROPOSED. Long axis along Y, Z ~3 to ~30 (low). Footprint 75 (Y) × 34 (X). Fore/aft trim slots to tune CG. Centroid ~**X −30** → inside the support triangle, lightly rear-biased (traction-positive). Aft edge held off the motor cylinders.
- **Rear (X −50 to −90): POWER / SERVICE CORRIDOR.** LOCKED zone. XT60, inline fuse (5–7.5 A blade, row 9/10), rocker switch (19×13 panel cutout, F4), reverse protector #5387, D24V22F5 buck. Reachable from the rear face without teardown.
- **Rear-center (~X −78, Y 0): CASTER.** PROPOSED. #2692, 3× M3. Mounts at Z=29 (see §4.3 — needs a ~28 mm reconciliation to the 57 deck).

**CABIN (Z ~57–90):**

- **Pi 3 (the dominant board, 85×56).** PROPOSED X −42 to +42, Y ±28, on M2.5 standoffs off the deck. Ports (USB/Ethernet, the tall edge) facing **−X (rear)** so cabling exits toward the service corridor. Clears wheel arches (Y ±77).
- **Electronics tier** — TB6612, KB2040, PCA9548 mux, ADS1115, BSS138 + band level-shift, 5-port hub, on Perma-Proto substrate beside/above the Pi. PROPOSED; exact placement after Pi stack height is measured (drives whether this tier is co-planar or stacked).

**RIDGE / FRONT-TOP (on/above shell, front):** camera centered, 2× VL53L4CD flanking, WS2812 LED band. Detailed in a later shell pass; here only its wire drops are reserved (§6).

---

## 3. Proposed Z-stack / layering

- **0–27.5:** wheels (sides), motor bellies, **battery** (Z 3–30, mid-rear), caster ball (rear).
- **27.5–52.5:** motor cylinders across the wheel line.
- **~53–57:** solid deck plate (the rigid safety datum; motors hang below it on cradles).
- **57–~84:** cabin — Pi on standoffs (~62 board, ~84 tallest component) + electronics tier.
- **~84–90:** thermal gap + top-shell wall.
- **>90:** ridge + reserved camera tilt envelope (v1.5).

The underside is **not flat**: deck at 57 across front/mid; the rear caster (29 mm) reaches the floor via a separate **height-tunable pod/shim**, not a one-shot plate step (§4.3).

---

## 4. Collision risks (attacked hard)

**4.1 — Motor-vs-motor at centerline.** Two 67 mm motors on a common axle in a ~180 mm body reach inboard to ~Y ±8, leaving a **~16 mm central channel** at the wheel line. Consequence: nothing wide lives low at X=0 — not the battery (34 wide), not a centered board. The basement center is *consumed by the motor sandwich*. **MEASURE wheel track (§1.4) — it directly sets this gap; if the collet stack pushes the wheels out, the gap shrinks further or the motors foul the frame.**

**4.2 — Battery-vs-motor, and the CG window (the central finding).** The battery (26.5 tall) sitting directly under the motors at X=0 puts its top at ~29.5 vs the motor belly 27.5 — a **~2 mm interference**. So it can't sit centered low at the axle line. Shifting it forward into the clear front-mid is **currently rejected on stability grounds**: it moves CG toward — and possibly ahead of — the support triangle, which risks a forward tip. **This is a design rejection pending proof, not settled physics** (Q correction): the exact no-tip line depends on real masses (Pi, shell, nose, motors, caster, wiring) and must be validated by a **mass mock-up / CG check before final CAD**. On that basis the battery is **placed in the aft window (X −13 to −47)**, CG ~X−30, inside the wheels↔caster triangle. PROPOSED. The fore/aft trim travels only within this aft window — it cannot cross the motor wall at X−12.5. (Cabin-mounting the battery was considered and rejected: it raises CG against F2 and steals Pi cabin volume; low-and-aft wins on CG.) **This is the tightest packaging constraint in the build.**

**4.3 — Caster height vs deck (the ~28 mm reconciliation).** Caster is 29 mm tall; its mount base sits at Z=29 to put the ball on the floor, while the deck is at 57 — a ~28 mm gap to bridge at the rear. Q split this correctly into two filings: the **shim height is MEASURE/COMPUTE** (caster contact height + shim stack, off the in-hand part), but the **physical bridge is OPEN DESIGN** — stepped rear plate vs separate caster pod vs bolted shim block vs printed replaceable shoe. **Q lean (and mine): a separate height-tunable caster pod/shim block, NOT a one-shot step baked into the safety plate** — it keeps the safety deck flat and stiff and lets ride height be tuned without reprinting a safety-critical part (cost: one added joint to keep tight). **Dependency note (Claude correction to the audit): deck height is gated by the cradle geometry; the caster pod is _downstream_ of the deck — it is sized to match whatever the deck turns out to be, not a gate on it.**

**4.4 — Wheel arches into the cabin.** Wheel top is 80; deck is 57. The wheels stand **23 mm above the deck plane** at the sides, so the cabin can't run full-width — wheel arches intrude at Y ±77 around X=0. The Pi (Y ±28) clears, but the electronics tier must not extend into the arches. PROPOSED arch keep-outs: Y beyond ±70 in the band X −20 to +20.

**4.5 — Cliff cone vs nose window.** Standing risk from v1.1 (A7): the cliff sensors are chassis-owned but their windows pass through the swappable nose. Every nose must clear the 18° cone unclipped. Layout consequence: the cliff bay (X +50–85, chassis) and the nose window apertures must be co-registered at the `FRONT_MODULE_INTERFACE_DATUM`. Flagged, governed by the existing interface rule.

**4.6 — Pi thermal (F15) — OPEN DECISION, not a shell afterthought.** Pi 3 in a ~27 mm enclosed cabin with the body sealed → throttle risk; ~6 mm over the tallest component is not enough air alone. Per Q, this is promoted from "shell later" to a **layout constraint now**. Reserve, at the layout level: a top vent path, a side vent path, a service hatch above the Pi, wire clearance above the GPIO/USB/CSI, and a minimum air gap over the tallest Pi component. **Air path first, heatsinks second** — the CanaKit heatsinks (row 42) are a supplement, not the solution. **OPEN DECISION — Pi thermal/service architecture.**

**4.7 — Checks to clear before commit (Q's seven).** None are resolved by this pass; each is a verification the CAD must satisfy:
1. **Battery strap vs basement wiring** — the strap must not crush encoder leads, motor leads, or the pack-sense divider.
2. **XT60 unplug room** — finger/hand clearance to pull it; a connector that needs needle-nose pliers is not serviceable.
3. **SD/USB vs Pi orientation** — a Pi placement that solves height but blocks the SD card fails the service rule (ties F14).
4. **Cliff-ToF cable bend radius** — front-underside STEMMA/Qwiic cables can't fold sharply into the plate.
5. **TB6612 heat + motor-wire exit** — driver wants short motor runs but must not be buried under the battery or Pi.
6. **Fuse access** — replaceable without removing the battery or the safety deck.
7. **Balance-lead / LiPo-alarm access** — the balance lead (alarm plug) must stay reachable after the battery is strapped in.

---

## 5. Service-access risks

- **Battery swap — the forced decision.** The battery is in the basement under the solid safety deck. It **cannot be reached without either pulling the deck (forbidden) or a dedicated access door.** The battery side/bottom door — previously deferred to v1.5 — is now **forced to a v1 decision**, because between-session swap + storage-charge (F3) is a routine operation and the design rule forbids removing the safety plate to service. **OPEN DECISION — V1-BLOCKING** (§7/§8).
- **Pi SD access (F14).** microSD is on the Pi underside edge; in the cabin under the top shell. Lifting the shell exposes the Pi, but the SD may need partial Pi lift. PROPOSED: orient Pi so the SD edge faces a shell access cut; confirm after Pi placement. Ties the F14 corruption mitigation (graceful LVC shutdown / read-only rootfs).
- **Rear corridor crowding.** XT60 + fuse + switch + #5387 + buck + the caster step all want rear volume. PROPOSED: caster on centerline, power components flanking it L/R, all reachable from the rear face. Risk: the rocker-switch panel cutout (F4) isn't yet in CAD.
- **E-stop.** External, cuts motor rail only, Pi stays alive (LOCKED behavior). Actuator type + placement **OPEN**; must land on the rear or a side reachable without opening the body.

---

## 6. Wire-channel routes

- **Cliff → mux → Pi:** from each front pocket (X+50–85, Z<57) up a protected channel through the front-mid clear zone to the PCA9548 (cabin), then to Pi I²C. STEMMA QT. Must not be pinched by a nose swap.
- **Motors → TB6612 + BSS138 → Pi/KB2040:** motor power + encoder leads from X=0 basement up into the cabin. **Keep motor-power runs away from the ADS1115 pack-sense and sensor I²C** (v1.1 B1 — motor noise corrupts pack-V reads).
- **Battery power chain:** XT60 (rear) → fuse → switch → #5387 → protected bus → buck → Pi. Short fat runs (≥20 AWG on the pack lead), all in the rear corridor.
- **LED band:** KB2040 (cabin) → 3.3→5 V level shift → band on the ridge (front-top). Long cabin-to-ridge run; route with the camera flex.
- **Camera:** Pi CSI → 610 mm flex (row 36) → ridge camera. Generous slack; route away from motor-noise.

---

## 7. Decisions still blocking CAD

**MEASURE — CAD-gating (numbers, off in-hand parts):** Pi stack height · #4885 faceplate hole spacing + boss · encoder backshell length · **wheel track (collet stack)** · battery dims confirm (75×34×26.5 + swell) · caster contact height + shim stack · wire-channel dims · **battery-door clearance**.

**COMPUTE (gated, not free):**
- **Deck height** — gated by the **cradle geometry** (the caster pod is *downstream* of this, not a co-gate; §4.3).
- **Battery CG** — requires a **physical mass mock-up / CG check before final CAD** (§4.2); the aft-window placement is accepted as current best layout, not proven.

**OPEN DECISION (a choice, not a number):**
- **Battery access door — V1-BLOCKING** (§5; was deferred to v1.5, now mandatory).
- **Pi thermal/service architecture** (§4.6, F15).
- **D4** plate-to-frame fastener (carried from footprint).
- **Fuse rating** (~5 A indicated by inventory rows 9/10; confirm vs wire gauge + stall).
- **E-stop actuator + placement** (§5).
- **Pi SD access strategy** (§5, F14).

**OPEN DESIGN (architecture, not yet drawn):**
- **Rear caster bridge** — pod / shim block / shoe (§4.3; Q lean: tunable pod, not a one-shot plate step).
- **Battery final X within the aft window** (CG trim; §4.2).

---

## 8. Q sign-off conditions (folded into this revision)

PASS_1 now carries these, per Q's audit, as the conditions for commit:
- **Battery access is V1-blocking.** The LiPo must be removable for charging, storage-voltage handling, inspection, and emergency removal **without removing the safety deck.** *(Q lock: any LiPo that can't be removed without disturbing the safety chassis is mounted wrong.)*
- **The aft-window battery placement** is accepted as current best layout but **must be validated by mass mock-up / CG check before final CAD.**
- **Rear caster height** requires a replaceable/tunable pod or shim strategy; do not bake a one-shot rear step into the whole plate until measured.
- **Pi thermal path and service access are layout constraints**, not shell afterthoughts.
- **CAD-gating measurements:** wheel track, collet stack, Pi stack height, motor boss geometry, encoder backshell, battery dims, wire-channel dims, and battery-door clearance.

---

## Bottom line

The basement is a **motor sandwich**: two long motors consume the wheel line and its center, placing the battery in a narrow aft window (X −13 to −47, CG ~X−30) — accepted as the best layout but **owed a mass-mock-up proof before CAD**, not asserted as physics. The 29 mm caster reaches the floor on a **tunable pod**, not a baked-in plate step. The battery's basement location makes the **access door V1-blocking** — a deferred decision the geometry promoted to mandatory. The Pi fits but needs a **designed air path**, not hope. None of this is CAD-final; it is a coordinate skeleton with every soft number flagged for the bench. **LiPo access first; the skeleton obeys the parts.**

*Cycle: Claude pass → Q audit (5 fixes + 7 checks, folded) → **Darrell ratify** → commit. One Claude amendment to the audit: deck height gates the caster pod, not vice-versa (§4.3).*

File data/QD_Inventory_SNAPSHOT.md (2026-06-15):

# QD Electronics Inventory — text snapshot (2026-06-14)

Plain-text fallback of the master spreadsheet. If the .xlsx ever won't open, this and the CSVs hold the same data.

**Totals:** 93 inventory line items · 29 flags/questions

**Latest summary:** Bench instruments: Tacklife MDC02 DC supply (CC limit = safe first power-on; develop OFF the LiPo; verify ~5A ceiling vs motor stall) + Hantek DSO5102P 2ch 100MHz scope (signal-integrity debug for F1 encoder / F9 WS2812 / F10+F12 I2C / F13 rail noise / F18 PWM). With the DMM = full diagnostic trio (meter/supply/scope).

## Inventory

### 1. Raspberry Pi 3  —  [Committed: QD v1]
- **Qty:** 1 board · **Subsystem:** Compute · **Mfr/Part:** Raspberry Pi 3
- **QD verdict:** Core
- **Notes:** CanaKit Complete Starter Kit (32GB). Model B/B+ - confirm (Q5). ~26 usable GPIO; I2C/SPI/I2S/PWM. Comes OUT of CanaKit case -> M2.5 standoffs (F7). Enclosed-body heat -> F15. SD-corruption on power-loss -> F14.

### 2. Pi Global Shutter Camera (wide-angle)  —  [Committed: QD v1]
- **Qty:** 1 unit · **Subsystem:** Sensing · **Mfr/Part:** Raspberry Pi GS
- **QD verdict:** Core
- **Notes:** Global Shutter, CS-mount (PID 5702). 6mm wide lens + 24in flex now logged separately. Confirmed.

### 3. ToF distance sensor VL53L4CD  —  [Committed: QD v1]
- **Qty:** 2 unit · **Subsystem:** Sensing · **Mfr/Part:** Adafruit 5396 (VL53L4CD)
- **QD verdict:** Core
- **Notes:** STEMMA QT breakout, ~1-1300mm. Both addr 0x29 -> isolate via PCA9548 mux. Ridge-mounted, flank camera.

### 4. 47:1 Metal Gearmotor 25Dx67L LP 12V, 48 CPR encoder  —  [Committed: QD v1]
- **Qty:** 2 unit · **Subsystem:** Drive · **Mfr/Part:** Pololu 4885
- **QD verdict:** Core
- **Notes:** 12V LP, stall 0.9A, free-run 60mA. 4mm D-shaft. Enc: 2248.86 cts/output-rev. ENCODER Vcc 3.5-20V, outputs swing to Vcc — see Flag F1.

### 5. Multi-Hub Wheel 80x10mm, 3/4mm inserts, black  —  [Committed: QD v1]
- **Qty:** 2 wheel (1x 2-pack) · **Subsystem:** Drive · **Mfr/Part:** Pololu 3690
- **QD verdict:** Core — verify vs TPU plan
- **Notes:** 4mm insert fits motor shaft. 80mm dia > 72mm body height — see Flag F2. Locked design called for printed TPU wheels.

### 6. TB6612FNG Dual Motor Driver Carrier  —  [Committed: QD v1]
- **Qty:** 1 board · **Subsystem:** Drive · **Mfr/Part:** Pololu 713
- **QD verdict:** Core
- **Notes:** 1.2A cont / 3.2A peak per ch. Survives 0.9A LP stall. VMOT max 13.5V > 12.6V pack OK. Needs PWMx2+4 dir+STBY GPIO.

### 7. Ball Caster, 1in plastic ball + bearings  —  [Committed: QD v1]
- **Qty:** 1 unit · **Subsystem:** Drive · **Mfr/Part:** Pololu 2692
- **QD verdict:** Core
- **Notes:** 3rd contact point -> differential drive. Caster+shim height must match wheel axle for level deck — see Flag F2.

### 8. D24V22F5 — 5V 2.5A Step-Down Regulator  —  [Committed: QD v1]
- **Qty:** 1 board · **Subsystem:** Power · **Mfr/Part:** Pololu 2858
- **QD verdict:** Core
- **Notes:** Buck for Pi/logic 5V rail. Input from 3S pack stays >5V across full discharge — no brownout.

### 9. Blade fuse assortment (ATO/ATC), 120pc  —  [Committed: QD v1]
- **Qty:** 1 kit · **Subsystem:** Power · **Mfr/Part:** Generic
- **QD verdict:** Core (5-7.5A); rest spare
- **Notes:** 5/7.5/10/15/20/25/30A. QD main fuse = 5A or 7.5A. 15A+ would pass enough to melt small wiring — do not use.

### 10. Inline blade fuse holder, ~16AWG leads  —  [Committed: QD v1]
- **Qty:** 10 unit · **Subsystem:** Power · **Mfr/Part:** Generic ATO
- **QD verdict:** Core (x1); 9 spare
- **Notes:** One installed in pack +lead. Standard ATO size. ~16AWG leads vs 22AWG bus — bracket both in crimp.

### 11. XT60H connectors, M+F, w/ insulating caps  —  [Committed: QD v1]
- **Qty:** 10 pair (tentative) · **Subsystem:** Power · **Mfr/Part:** Generic XT60H
- **QD verdict:** Core (x1); spare
- **Notes:** COUNT UNCONFIRMED. 60A rated (>>4A draw). Solder-cup — fill cup for 22AWG. Female on battery side.

### 12. Zeee 3S 2200mAh 50C LiPo (XT60)  —  [Committed: QD v1]
- **Qty:** 2 pack · **Subsystem:** Power · **Mfr/Part:** Zeee
- **QD verdict:** Core (x1 + swap/spare)
- **Notes:** 11.1V nom / 12.6V full / 24.42Wh. Ships XT60 (matches XT60H). STORE at 3.8V/cell between sessions. See Flags F3 (runtime LVC) + F2 (CG).

### 13. SKYRC iMAX B6AC V2 balance charger/discharger  —  [Bench equipment]
- **Qty:** 1 unit · **Subsystem:** Power / Support · **Mfr/Part:** SKYRC
- **QD verdict:** Support equip (off-board)
- **Notes:** AC/DC, 6A chg / 2A dischg, LiPo 1-6S. Balances 3S. Has STORAGE mode (3.8V/cell). Charge 3S at ~2.2A (1C), not 6A. Needs XT60 charge lead — see Flag F5.

### 14. DaierTek KCD1-101 SPST rocker switch + spade pigtails  —  [Committed: QD v1]
- **Qty:** 10 unit · **Subsystem:** Power / Control · **Mfr/Part:** DaierTek KCD1-101
- **QD verdict:** Core (x1); 9 spare
- **Notes:** ~6A. On/off between runs (saves XT60 cycles). Needs ~19x13mm panel cutout NOT in locked CAD — see Flag F4. Wire: fuse upstream of switch.

### 15. Fermerry 22AWG stranded silicone hookup wire, 6 colors  —  [Committed: QD v1]
- **Qty:** 150 ft (25ft x6) · **Subsystem:** Wiring · **Mfr/Part:** Fermerry
- **QD verdict:** Core
- **Notes:** Silicone = good for v1.5 ridge flex. 22AWG fine everywhere; thinnest acceptable on pack +lead (consider 20/18AWG there).

### 16. JST-XH 2.54mm connector kit (2P-10P) + pre-crimped silicone leads  —  [Committed: QD v1]
- **Qty:** 1 kit · **Subsystem:** Wiring · **Mfr/Part:** elechawk
- **QD verdict:** Core
- **Notes:** Body-to-ridge bus connector family. Inherently keyed. 6P = locked spec; 8P available if upsizing — but mux may collapse to 4-wire I2C. See Flag F6.

### 17. Heat-shrink tubing kit, 2:1, 1-8mm, 580pc  —  [Committed: QD v1]
- **Qty:** 1 kit · **Subsystem:** Wiring · **Mfr/Part:** Ginsco
- **QD verdict:** Core (consumable)
- **Notes:** -55 to +125C. Non-adhesive. Needs a HEAT GUN, not a lighter — confirm one is owned (tool note).

### 18. M2.5 brass standoff/screw/nut kit, 100pc  —  [Committed: QD v1]
- **Qty:** 2 kit (tentative) · **Subsystem:** Compute / Mounting · **Mfr/Part:** Geekworm
- **QD verdict:** Core
- **Notes:** COUNT TENTATIVE (1 open + 1 sealed). M2.5 = Pi standard (chassis is M3 — two fastener systems). Mount method undecided — see Flag F7.

### 19. STEMMA QT JST-SH 4-pin to male header cable  —  [Committed: QD v1]
- **Qty:** 4 cable · **Subsystem:** Wiring / Sensor · **Mfr/Part:** Adafruit 4209
- **QD verdict:** Core
- **Notes:** Breaks STEMMA QT I2C out to header pins (e.g. to Pi).

### 20. STEMMA QT / Qwiic JST-SH 4-pin cable, 150mm  —  [Committed: QD v1]
- **Qty:** 4 cable · **Subsystem:** Wiring / Sensor · **Mfr/Part:** Adafruit 4397
- **QD verdict:** Core
- **Notes:** Plug-and-play I2C chaining. JST-SH (1.0mm) — small; NOT ideal for flex joint vs JST-XH. See Flag F6.

### 21. PMSA003I Air-Quality (PM2.5) sensor, STEMMA QT  —  [QD v1.5+ / reusable]
- **Qty:** 1 unit · **Subsystem:** Sensing · **Mfr/Part:** Adafruit 4632
- **QD verdict:** Later (v1.5+)
- **Notes:** I2C particulate sensor — new environmental modality. Scope question vs locked v1 — see Flag F8.

### 22. PCA9548 8-channel I2C multiplexer, STEMMA QT  —  [Committed: QD v1]
- **Qty:** 2 board · **Subsystem:** Sensing / Infra · **Mfr/Part:** Adafruit 5626
- **QD verdict:** Core (infrastructure)
- **Notes:** Resolves ToF 0x29 address collision. One in ridge can collapse body-to-ridge run to 4-wire I2C. See Flag F6.

### 23. Magnetic reed contact switch, SPST-NO w/ leads  —  [QD v1.5+ / reusable]
- **Qty:** 4 unit · **Subsystem:** Sensing · **Mfr/Part:** Adafruit 375
- **QD verdict:** Later / TBD
- **Notes:** Reed + magnet (NOT vibration sensor). Possible use: swappable front-module presence/keying, or hatch sense. Confirm intent.

### 24. BNO085 9-DOF Orientation IMU (fusion)  —  [Committed: QD v1]
- **Qty:** 2 board · **Subsystem:** Sensing · **Mfr/Part:** Adafruit 4754
- **QD verdict:** Core (x1) + 2nd TBD
- **Notes:** Proprioception — addresses tip-over (F2). Known Pi I2C clock-stretch issue: use UART-RVC/SPI — see Flag F10. 2nd unit: body+ridge or spare? (open Q).

### 25. SPH0645LM4H I2S MEMS microphone  —  [QD v1.5+ / reusable]
- **Qty:** 2 board · **Subsystem:** Sensing · **Mfr/Part:** Adafruit 3421
- **QD verdict:** Later (v1.5+)
- **Notes:** AUDIO via I2S (not I2C) — separate Pi bus/GPIO. Two = stereo. PCM peripheral conflicts w/ WS2812 LED — see Flag F9.

### 26. Adafruit KB2040 (RP2040) co-processor  —  [Committed: QD v1]
- **Qty:** 1 board · **Subsystem:** Compute · **Mfr/Part:** Adafruit 5302
- **QD verdict:** Core? (decision)
- **Notes:** RP2040 MCU (free w/ order). Candidate real-time co-pro: Layer-1 reflex (deterministic), PIO quadrature for encoders, PIO WS2812 (sidesteps F9), I2S. Architecture decision -> Flag F11.

### 27. BSS138 4-ch I2C-safe logic level converter  —  [Committed: QD v1]
- **Qty:** 1 board · **Subsystem:** Wiring / Infra · **Mfr/Part:** Adafruit 757
- **QD verdict:** Core
- **Notes:** RESOLVES F1. 4 ch = 2 encoders x A/B. Encoder Vcc 5V -> BSS138 -> 3.3V Pi.

### 28. ADS1115 16-bit 4-ch ADC (PGA)  —  [Committed: QD v1]
- **Qty:** 2 board · **Subsystem:** Sensing / Infra · **Mfr/Part:** Adafruit 1085
- **QD verdict:** Core (1)
- **Notes:** Adds analog input to Pi (Pi has none). Enables F3: read pack V via divider for runtime low-voltage cutoff. Addr 0x48-0x4B strappable (2 coexist).

### 29. BME688 temp/humidity/pressure/gas sensor  —  [QD v1.5+ / reusable]
- **Qty:** 1 board · **Subsystem:** Sensing · **Mfr/Part:** Adafruit 5046
- **QD verdict:** Later (v1.5+)
- **Notes:** Environmental: gas/VOC + T/H/P. Complements PMSA003I (particulate). I2C STEMMA QT. Scope -> F8.

### 30. DRV5032 digital Hall-effect sensor  —  [QD v1.5+ / reusable]
- **Qty:** 2 board · **Subsystem:** Sensing · **Mfr/Part:** Adafruit/ScoutMakes 6051
- **QD verdict:** Later / TBD
- **Notes:** Magnet-presence switch. Overlaps reed (375). Likely front-module presence/keying. Confirm intent (Q4).

### 31. IR Break-Beam Sensor, 5mm LEDs  —  [QD v1.5+ / reusable]
- **Qty:** 2 pair · **Subsystem:** Sensing · **Mfr/Part:** Adafruit 2168
- **QD verdict:** Later (v1.5+)
- **Notes:** Emitter+detector beam-break (digital). Possible edge/tripwire/object-pass sense. Uses 3-pin JST-PH cable (3893).

### 32. DS3231 Precision RTC, STEMMA QT  —  [Committed: QD v1]
- **Qty:** 2 board · **Subsystem:** Sensing · **Mfr/Part:** Adafruit 5188
- **QD verdict:** Core (1); 2nd spare
- **Notes:** Real clock for timestamping significance/decay. FIXED addr 0x68 -> TWO CANNOT SHARE A BUS (collide). See F12.

### 33. Qwiic / STEMMA QT 5-Port Hub  —  [Committed: QD v1]
- **Qty:** 1 board · **Subsystem:** Sensing / Infra · **Mfr/Part:** Adafruit 5625
- **QD verdict:** Core
- **Notes:** Passive I2C fan-out (1->5). For UNIQUE-address devices. Use mux (not hub) for address-colliders (ToF, 2nd RTC).

### 34. Perma-Proto half-sized breadboard PCB  —  [Committed: QD v1]
- **Qty:** 6 board · **Subsystem:** Wiring / Proto · **Mfr/Part:** Adafruit 1609
- **QD verdict:** Core
- **Notes:** Solderable proto substrate for the internal electronics stack (level shifter, ADC, hub mounting).

### 35. 6mm 3MP Wide-Angle Lens, CS-mount  —  [Committed: QD v1]
- **Qty:** 1 unit · **Subsystem:** Sensing / Camera · **Mfr/Part:** Adafruit 4563
- **QD verdict:** Core
- **Notes:** Wide lens for the Global Shutter Camera (CS mount). This is the 'wide-angle' from records.

### 36. Flex cable for Pi Camera, 24in / 610mm  —  [Committed: QD v1]
- **Qty:** 1 cable · **Subsystem:** Sensing / Camera · **Mfr/Part:** Adafruit 1731
- **QD verdict:** Core
- **Notes:** Confirms the 24in camera flex from records. Fragile. Routes Pi CSI -> ridge camera.

### 37. STEMMA QT JST-SH 4-pin cables, assorted  —  [Committed: QD v1]
- **Qty:** 20 cable · **Subsystem:** Wiring · **Mfr/Part:** Adafruit 5385/5384/4401/4210
- **QD verdict:** Core
- **Notes:** This order: 400mm x4, 300mm x4, 200mm x4, 100mm x8. I2C chaining stock.

### 38. STEMMA JST-PH 2mm 3-pin to male header cable  —  [QD v1.5+ / reusable]
- **Qty:** 2 cable · **Subsystem:** Wiring · **Mfr/Part:** Adafruit 3893
- **QD verdict:** Later
- **Notes:** 3-pin (not 4) - pairs with the IR break-beam sensors.

### 39. PCB Coaster, gold Adafruit logo  —  [-]
- **Qty:** 1 unit · **Subsystem:** Swag / non-build · **Mfr/Part:** Adafruit 5719
- **QD verdict:** N/A (swag)
- **Notes:** Free promo item. Not a build part - logged for completeness.

### 40. microSD card, 32GB (Pi OS)  —  [Committed: QD v1]
- **Qty:** 1 card · **Subsystem:** Compute / Storage · **Mfr/Part:** CanaKit (SanDisk)
- **QD verdict:** Core
- **Notes:** Holds the OS. Abrupt power-off risks ext4 corruption -> graceful LVC shutdown and/or read-only rootfs (F14).

### 41. CanaKit 2.5A microUSB power supply  —  [Bench equipment]
- **Qty:** 1 unit · **Subsystem:** Power / Support · **Mfr/Part:** CanaKit
- **QD verdict:** Support (bench only)
- **Notes:** BENCH ONLY - powers Pi at desk. Rover Pi runs off D24V22F5 buck. Not a rover part.

### 42. CanaKit black case (Pi 3)  —  [Bench equipment]
- **Qty:** 1 case · **Subsystem:** Compute / Support · **Mfr/Part:** CanaKit
- **QD verdict:** Support (not in rover)
- **Notes:** Pi uses the printed QD chassis instead. Case = bench/spare. (Kit heatsinks DO carry to rover - see F15.)

### 43. Rii mini X1 wireless keyboard/touchpad  —  [Bench equipment]
- **Qty:** 1 unit · **Subsystem:** Support · **Mfr/Part:** Rii
- **QD verdict:** Support (bench tool)
- **Notes:** Bench input for Pi setup. Not a CanaKit item; not a rover part.

### 44. 37-in-1 Sensor Kit  —  [Free - library]
- **Qty:** 1 kit · **Subsystem:** Sensing / Proto · **Mfr/Part:** RobotLinking 37-in-1
- **QD verdict:** Bench/proto (not rover BOM, except picks)
- **Notes:** Breadboard learning kit. MOSTLY REDUNDANT w/ owned gear (Hall->DRV5032; temp/RH->BME688; sound->SPH0645; reed->375; tilt/shock->BNO085). ROVER PICKS: IR reflectance (down=cliff/edge), shock/tilt (impact/tip) -> reflex layer via KB2040 (F16). Buzzer = only audio OUTPUT in inventory. [Library stock for future builds.]

### 45. HC-SR501 PIR motion sensor  —  [Committed: QD v1]
- **Qty:** 5 unit · **Subsystem:** Sensing · **Mfr/Part:** HC-SR501 (BISS0001)
- **QD verdict:** Core candidate (at-rest only)
- **Notes:** Pyroelectric presence of moving warm bodies = strongest 'otherness'/significance input. INVALID WHILE MOVING (self-motion->false triggers): use at-rest only, gate on zero-velocity (F17). Out=3.3V (Pi-safe, no shifter); VCC 5V; 30-60s warmup. Set delay pot min, jumper H. LWIR opaque to shell -> domes must be exposed (F17).

### 46. DHT11 / DHT22(AM2302) temp-humidity modules  —  [Free - library]
- **Qty:** 7 unit · **Subsystem:** Sensing · **Mfr/Part:** DHT11 x5 + DHT22/AM2302 x2
- **QD verdict:** Bench/proto (redundant)
- **Notes:** REDUNDANT w/ BME688 (better accuracy/speed + adds pressure/gas). Single-wire bit-bang = worst-case on a Pi (non-RT scheduler -> CRC fails). If ever used: KB2040 only, never Pi. DHT11 count ~5 (confirm). [Library stock for future builds.]

### 47. Dupont jumper wires, assorted (F-F / F-M / M-M)  —  [Free - library]
- **Qty:** 3 bundle · **Subsystem:** Wiring · **Mfr/Part:** Generic
- **QD verdict:** Bench/proto consumable
- **Notes:** For breadboard bring-up (validate sensors loose before solder/JST). Not rover BOM. [Library stock for future builds.] [+2 Elegoo kits (F-F/F-M/M-M) = qty 3; now includes M-M. F-M = Pi/breakout pins to breadboard, workhorse for sensor-bus bring-up.]

### 48. Solar panel, mini poly ~68x37mm  —  [Free - library]
- **Qty:** 10 unit · **Subsystem:** Power · **Mfr/Part:** RY9-38 (rating unmarked)
- **QD verdict:** Library (not v1)
- **Notes:** TOY BOX. Form factor confirmed (68x37mm). RATING NOT PRINTED -> measure Voc/Isc in sun (typical ~5-6V/30-60mA for size, verify). Condition: intact, solar ages well. QD: NOT v1 power (3S needs 12.6V + charge mgmt; naive solar->LiPo is unsafe); light-sensor role redundant w/ photoresistors. Good for standalone solar project. Provenance/rating: ask Darrell. [Library stock.]

### 49. DIY Solar Power Box (self-built)  —  [None]
- **Qty:** 1 unit · **Subsystem:** Power / Equipment · **Mfr/Part:** Self-built; Stack-On case
- **QD verdict:** Equipment (not QD)
- **Notes:** Self-built portable solar power station. Components: Renogy PWM charge controller; 2x ExpertPower SLA ~12V 9Ah (EXP1290-class, AGM); fused distribution block; watt-meter/power analyzer; 3 panel rockers; sunvisor panels. CONDITION: electronics fine; SLA PAIR is aging risk -> sulfation if stored unmaintained; test rested V (>12.6 healthy) + load before trust; likely REPLACE. Vent before charging SLA in sealed steel box. QD: NOT a part (12V lead-acid vs 3S LiPo; controller is PbA-profiled). Usable as 12V bench/field supply; components harvestable.

### 50. Relay module, 4-channel (opto-isolated)  —  [Free - library]
- **Qty:** 1 board (4 relays) · **Subsystem:** Power / Switching · **Mfr/Part:** Songle SRD-05VDC-SL-C x4
- **QD verdict:** Library (not QD)
- **Notes:** 5V coils; 10A 250VAC / 10A 30VDC SPDT; opto-isolated ACTIVE-LOW inputs; JD-VCC jumper isolates coil from logic power. CONDITION: fine (no electrolytics; relays/optos age well). QD: NO - wrong for DC mobile robot (coil ~80mA standing each = drain vs F13; can't PWM; QD switching is PWM->MOSFET or solid-state via TB6612 STBY). GOOD FOR: mains/AC switching, home automation (10A 250VAC + isolation). [Library stock.]

### 51. Photoresistor, CdS (GL5528 likely)  —  [QD candidate (v1.5+)]
- **Qty:** 20 pcs · **Subsystem:** Sensing · **Mfr/Part:** Gikfun EK1412 (GL55xx)
- **QD verdict:** Candidate v1.5+ (light sense)
- **Notes:** ~10-20k light / ~1M dark; analog via ADS1115. ON-THESIS as light-significance input (shadow/dusk/lights-on). NOTE: camera already gives luminance free; CdS slow/drifty; VEML7700/TSL2591 = precise route. Not v1 (F8 creep). CONDITION: fine. CdS=cadmium (RoHS; fine for hobby).

### 52. White LED emitter, round  —  [Free - library]
- **Qty:** 100 pcs · **Subsystem:** Output / Light · **Mfr/Part:** Yootop (X001TL48LH)
- **QD verdict:** Library (poss. 1-2 cam fill-light)
- **Notes:** White, Vf ~3-3.4V (blue die + yellow phosphor). NOT addressable (!= WS2812 debug band). Exact bead wattage/package TENTATIVE (look small/low-power). QD: maybe 1-2 as low-light camera illumination; rest library. CONDITION: fine.

### 53. Reed switch, glass axial (SPST-NO)  —  [Free - library]
- **Qty:** 20 pcs (approx) · **Subsystem:** Sensing · **Mfr/Part:** Generic glass reed (E383)
- **QD verdict:** Library / spare (dock-detect v1.5?)
- **Notes:** CONFIRMED reed switches (close-up: overlapping blades + contact gap in glass envelope). ~20 pcs. Passive SPST-NO, closes near magnet, ZERO standing power, reads on GPIO+pullup (no ADC/I2C). QD: NOT v1 (core=cam+ToF+IMU). Best potential job = zero-power charging-dock presence detect (v1.5+); for moving-chassis magnetics DRV5032 Hall wins (solid-state, vibration-immune). See Q4. CONDITION: fine but FRAGILE glass - bend leads away from seal; store in clamshell.

### 54. High-power COB LED, white ~50W  —  [Free - library]
- **Qty:** 1 pcs · **Subsystem:** Output / Light · **Mfr/Part:** Generic COB (~40mm)
- **QD verdict:** Library (NOT QD)
- **Notes:** ~40mm sq, ~100-die array, Vf ~30-34V, ~50W class (30-100W; no wattage stamp = TENTATIVE). Needs CC driver + real heatsink. QD: NO - 30V+ off 3S needs boost; flattens 2200mAh in minutes; cooks sealed body. GOOD FOR: floodlight/work light. CONDITION: fine.

### 55. Trimmer pot, assorted 100R-100k  —  [Bench/library]
- **Qty:** 8 pcs (approx) · **Subsystem:** Passives / Bench · **Mfr/Part:** 3362/3386-style (B taper)
- **QD verdict:** Bench/library (not QD)
- **Notes:** Blue single-turn trimpots. Codes 101/102/103/104 = 100R/1k/10k/100k; B=linear. QD: NO native use (digital/I2C, nothing to trim). Bench/breadboard analog stock. CONDITION: fine (wipers look unused; contact cleaner if scratchy).

### 56. ESP32 dev board w/ OLED (WiFi Kit 32)  —  [Bench/library]
- **Qty:** 1 pcs · **Subsystem:** Compute / Tools · **Mfr/Part:** Heltec HTIT-WB32
- **QD verdict:** Bring-up tool (off-board telemetry)
- **Notes:** ESP32 dual-core (WiFi+BT); 0.96" SSD1306 OLED (I2C); CP2102 USB-UART; 8MB flash (W25Q64); onboard 1S LiPo charge + JST. QD: NOT compute (Pi+KB2040 cover brain+reflex; WiFi dup of Pi). Onboard OLED OFF-THESIS (screen reads as 'gadget'; LED band = creature-like affect, no literal readout). BEST USE: OFF-board wireless telemetry dashboard for bring-up (Pi -> WiFi/ESP-NOW -> OLED: live batt V / mode / significance, untethered). Ties Gate B / first power-on. CONDITION: fine.

### 57. ESP32 dev board, bare (WROOM-32)  —  [Bench/library]
- **Qty:** 5 pcs · **Subsystem:** Compute / Tools · **Mfr/Part:** ESP32 DevKit (generic)
- **QD verdict:** Library / opt. bring-up remote
- **Notes:** ESP32-WROOM-32; WiFi+BT+BLE; micro-USB; CP2102 UART; AMS1117 3V3. NO OLED / NO LiPo charger (cf Heltec). QD: NOT compute (Pi+KB2040 settled; WiFi dup of Pi). No screen = not a dashboard. OPTIONAL: ESP-NOW manual-drive/override remote for bring-up (pairs w/ Heltec readout = untethered cockpit). NOT a safety e-stop - reflex stays onboard KB2040. Else general dev/library. CONDITION: fine. [+3 ESP32 DevKit V1 (WROOM-32, back-silk confirmed) added same verdict = qty 5 total.]

### 58. ESP8266 dev board (NodeMCU + D1 Mini)  —  [Bench/library]
- **Qty:** 5 pcs · **Subsystem:** Compute / Tools · **Mfr/Part:** HiLetgo NodeMCU x4 + Wemos D1 Mini x1
- **QD verdict:** Library / dev spare
- **Notes:** ESP8266MOD (ESP-12E); WiFi-ONLY (no BT/BLE); CP2102 UART; micro-USB; Vin 5V rec / 10V max; single-core, fewer GPIO than ESP32. QD: NOT compute (Pi+KB2040 settled; weaker than ESP32s already ruled out; WiFi dup of Pi). Speaks ESP-NOW so *could* be bring-up node/remote, but ESP32 is better - deeper-bench spare. MCU CATEGORY CLOSED/over-stocked: 3x ESP32 + 4x ESP8266 = 7 WiFi MCUs, none on QD; any further WiFi MCU = same verdict. CONDITION: fine (straighten bent header pins). [+1 Wemos/LOLIN D1 Mini (ESP8266, compact FF w/ LOLIN shield ecosystem) = qty 5. Same verdict.]
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

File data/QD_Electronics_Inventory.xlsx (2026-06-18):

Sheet: Inventory
QD — Electronics Inventory
In hand unless noted. 'Per records' rows are not yet photo-verified.
ID | Component | Mfr / Part # | Subsystem | Qty | Unit | Status | QD v1 Use | Key Specs / Notes | Supplier | Source / Order | Photo | Allocation / Reuse | Summary
1 | Raspberry Pi 3 | Raspberry Pi 3 | Compute | 1 | board | In hand (photo) | Core | CanaKit Complete Starter Kit (32GB). Model B/B+ - confirm (Q5). ~26 usable GPIO; I2C/SPI/I2S/PWM. Comes OUT of CanaKit case -> M2.5 standoffs (F7). Enclosed-body heat -> F15. SD-corruption on
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

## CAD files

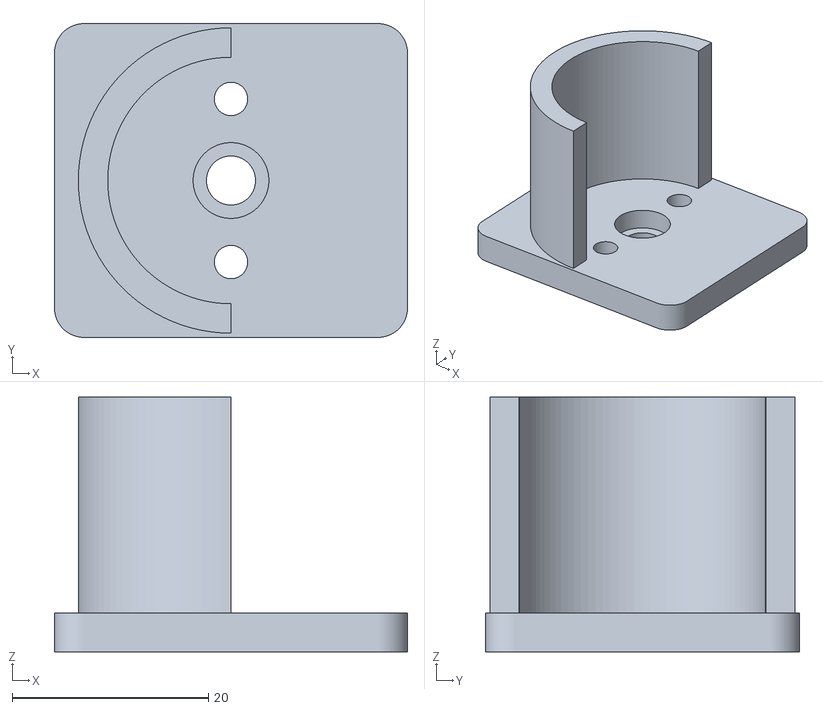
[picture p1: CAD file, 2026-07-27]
specs/coupon_revA.stl
36.0 x 32.0 x 26.0

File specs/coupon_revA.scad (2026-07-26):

// QD Motor Cradle - Coupon Rev A (fit test)
// Traces to V1_CRADLE_SPEC_PASS_1.md @ f6377c7
// Units = millimeters. To tune for Rev B, change only the numbers in the
// "PROVISIONAL" block below, then re-export the STL.

// ---------- MEASURED (fixed - do not change) ----------
body_OD     = 24.79;      // motor body outer diameter
boss_D      = 6.93;       // center brass hub diameter
boss_H      = 2.42;       // center brass hub height
hole_offset = 16.63 / 2;  // half the M3 face-hole spacing = 8.315

// ---------- PROVISIONAL (tune these for Rev B) ----------
C_cup        = 0.35;               // saddle clearance, DIAMETRAL
C_hole       = 3.4;                // M3 through-hole diameter
D_pocket     = 0.40;               // boss pocket radial clearance
H_pocket     = 0.40;               // boss pocket axial clearance
T_plate      = 4.0;                // face-wall thickness
shaft_hole_D = 5.0;                // clearance hole for the 4mm shaft
saddle_len   = 22;                 // how far the trough runs
saddle_wall  = 3.0;                // trough wall thickness

// ---------- derived (leave alone) ----------
cup_ID       = body_OD + C_cup;        // 25.14
cup_OD       = cup_ID + 2*saddle_wall; // 31.14
pocket_D     = boss_D + 2*D_pocket;    // 7.73
pocket_depth = boss_H + H_pocket;      // 2.82
fp_x = 36; fp_y = 32; fillet = 3;
$fn = 96;

module rrect(x, y, r) {
  hull() for (sx=[-1,1]) for (sy=[-1,1])
    translate([sx*(x/2-r), sy*(y/2-r)]) circle(r);
}

difference() {
  union() {
    // face wall (sits flat on the bed)
    linear_extrude(T_plate) rrect(fp_x, fp_y, fillet);
    // saddle trough (half-pipe, opens upward), rises off the wall
    translate([0,0,T_plate])
      linear_extrude(saddle_len)
        difference() {
          circle(d=cup_OD);
          circle(d=cup_ID);
          translate([cup_OD/2,0]) square([cup_OD, cup_OD], center=true);
        }
  }
  // central shaft clearance hole
  translate([0,0,-0.1]) cylinder(h=T_plate+0.2, d=shaft_hole_D);
  // boss pocket (opens up on the motor-mating face)
  translate([0,0,T_plate-pocket_depth]) cylinder(h=pocket_depth+0.1, d=pocket_D);
  // two M3 through-holes
  for (sy=[-1,1]) translate([0, sy*hole_offset, -0.1]) cylinder(h=T_plate+0.2, d=C_hole);
  // recessed "L" for left-hand identification
  translate([-fp_x/2+5, 0, -0.1]) linear_extrude(0.8)
    text("L", size=6, halign="center", valign="center");
}

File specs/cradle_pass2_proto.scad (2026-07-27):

// QD Motor Cradle - Pass 2 PROTOTYPE
// Source specification: V1_CRADLE_SPEC_PASS_2.md @ 05e382b
// PROTOTYPE - NOT ROVER_INTERFACE_VERIFIED. May earn CRADLE_STRUCTURE_VERIFIED on the fixture only.
// Units = mm. Choose the part to render with the "part" variable, then F5/F6/F7 to export STL.
// Rev-B tuning: change ONLY the PASS-2 block. The INHERITED block is FIT_VERIFIED - do not change.

part = "cradle";   // "cradle" | "strap" | "fixture" | "all"

// ===== INHERITED - Rev-A FIT_VERIFIED (FROZEN) =====
body_OD      = 24.79;
boss_D       = 6.93;
boss_H       = 2.42;
hole_offset  = 16.63/2;   // 8.315
cup_ID       = 25.14;     // C_cup 0.35 diametral
C_hole       = 3.4;
pocket_D     = 7.73;
pocket_depth = 2.82;
T_plate      = 4.0;
shaft_hole_D = 5.0;
saddle_len   = 22;
saddle_wall  = 3.0;
cup_OD       = cup_ID + 2*saddle_wall;   // 31.14

// ===== NEW - Pass-2 structural (tunable) =====
strap_gap      = 1.0;    // retention play - strap ceiling above motor
strap_boss_top = 4.0;    // boss height above equator = HARD COMPRESSION STOP
strap_boss_Y   = 17.0;
strap_boss_D   = 8.0;
strap_bar_w    = 12;
strap_thick    = 4.0;
strap_bolt_D   = 3.4;    // M3 clearance in strap feet
strap_insert_D = 4.2;    // M3 heat-set insert bore in bosses (tune to your inserts)
foot_thick     = 5.0;
foot_ear_Y     = 28;
foot_hole_Y    = 25;
foot_hole_D    = 3.4;
block_halfY    = 22;

// ===== derived =====
motor_r   = body_OD/2;                 // 12.395
bar_under = motor_r + strap_gap;       // 13.395  <- strap ceiling (compression-stop chain)
foot_botX = -(cup_OD/2 + foot_thick);  // -20.57
boss_z0 = 6; boss_z1 = 16; boss_zc = (boss_z0+boss_z1)/2;   // strap-boss span / center
fz1 = 3; fz2 = saddle_len - 3;                              // foot hole Z
fixture_thk = 8; fixture_Y = foot_ear_Y + 8;
$fn = 96;

module rrect(x,y,r){ hull() for(sx=[-1,1]) for(sy=[-1,1]) translate([sx*(x/2-r), sy*(y/2-r)]) circle(r); }

// ---------- CRADLE ----------
module cradle(){
  difference(){
    union(){
      // main body block: X foot_botX..0, Y +-block_halfY, Z -T_plate..+saddle_len
      translate([foot_botX, -block_halfY, -T_plate])
        cube([-foot_botX, 2*block_halfY, T_plate + saddle_len]);
      // foot ears (bottom slab widened in Y for accessible mounting)
      translate([foot_botX, -foot_ear_Y, 0])
        cube([foot_thick, 2*foot_ear_Y, saddle_len]);
      // strap-mount bosses (rise +X from equator to the hard-stop face)
      for(sy=[-1,1])
        translate([0, sy*strap_boss_Y - strap_boss_D/2, boss_z0])
          cube([strap_boss_top, strap_boss_D, boss_z1 - boss_z0]);
    }
    // motor bore -> 180 deg trough (block only exists for X<0)
    translate([0,0,-0.01]) cylinder(h=saddle_len+0.02, r=cup_ID/2);
    // datum-face features
    translate([0,0,-T_plate-0.01]) cylinder(h=T_plate+0.02, d=shaft_hole_D);      // shaft
    translate([0,0,-pocket_depth]) cylinder(h=pocket_depth+0.02, d=pocket_D);      // boss pocket
    for(sy=[-1,1]) translate([0, sy*hole_offset, -T_plate-0.01])                   // 2x M3
      cylinder(h=T_plate+0.02, d=C_hole);
    // strap insert bores (down -X into each boss)
    for(sy=[-1,1]) translate([strap_boss_top+0.01, sy*strap_boss_Y, boss_zc])
      rotate([0,-90,0]) cylinder(h=6, d=strap_insert_D);
    // foot mount holes (through the ears, +X)
    for(sy=[-1,1]) for(zz=[fz1,fz2])
      translate([foot_botX-0.01, sy*foot_hole_Y, zz]) rotate([0,90,0])
        cylinder(h=foot_thick+0.02, d=foot_hole_D);
    // L identification (recessed, +Y ear top)
    translate([foot_botX+foot_thick-0.6, foot_hole_Y, saddle_len/2])
      linear_extrude(0.8) text("L", size=6, halign="center", valign="center");
    // keying notch (asymmetric - +Y ear only)
    translate([foot_botX-0.01, foot_ear_Y-3, saddle_len-3])
      cube([foot_thick+0.02, 4, 4]);
  }
}

// ---------- STRAP (removable retention, compression-limited) ----------
module strap(){
  difference(){
    union(){
      // top bar underside at X = bar_under (the fixed ceiling over the motor)
      translate([bar_under, -(strap_boss_Y+strap_boss_D/2), boss_zc - strap_bar_w/2])
        cube([strap_thick, 2*(strap_boss_Y+strap_boss_D/2), strap_bar_w]);
      // two feet: from boss top (hard stop) up to the bar
      for(sy=[-1,1])
        translate([strap_boss_top, sy*strap_boss_Y - strap_boss_D/2, boss_zc - strap_bar_w/2])
          cube([bar_under - strap_boss_top + 0.01, strap_boss_D, strap_bar_w]);
    }
    // bolt holes through feet + bar into boss inserts
    for(sy=[-1,1]) translate([strap_boss_top-0.01, sy*strap_boss_Y, boss_zc])
      rotate([0,90,0]) cylinder(h=bar_under - strap_boss_top + strap_thick + 0.02, d=strap_bolt_D);
  }
}

// ---------- FIXTURE (rigid stand-in for the skeleton; prototype rig) ----------
module fixture(){
  difference(){
    translate([foot_botX - fixture_thk, -fixture_Y, -8])
      cube([fixture_thk, 2*fixture_Y, saddle_len + 16]);
    // insert/tapped holes matching the foot ears
    for(sy=[-1,1]) for(zz=[fz1,fz2])
      translate([foot_botX+0.01, sy*foot_hole_Y, zz]) rotate([0,90,0])
        cylinder(h=fixture_thk+0.02, d=strap_insert_D);
    // vise-grip relief slots (optional clamp points)
    for(sy=[-1,1]) translate([foot_botX - fixture_thk-0.01, sy*(fixture_Y-4), saddle_len/2])
      rotate([0,90,0]) cylinder(h=fixture_thk+0.02, d=6);
  }
}

if (part=="cradle") cradle();
else if (part=="strap") strap();
else if (part=="fixture") fixture();
else { // "all" - preview only, do NOT export as one STL
  cradle();
  color("orange") strap();
  color("gray") translate([-6,0,0]) fixture();
}

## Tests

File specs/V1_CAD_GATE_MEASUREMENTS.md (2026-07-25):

# V1_CAD_GATE_MEASUREMENTS

> **What this is:** a measurement gate. Every row is a physical number **CAD is forbidden to guess** — it must come off a manufacturer drawing (confirm), the in-hand part (calipers / scale), or be computed from one that did. NOT a design doc, NOT CAD geometry. It exists so no curve gets drawn around an assumed dimension.
>
> Built from the CAD-gating items in `V1_MASTER_FOOTPRINT_AND_BOTTOM_PLATE_CONSTRAINTS.md` (`60810ce`+) and `V1_COMPONENT_LAYOUT_PASS_1.md` (`5b7b7b3`). Drafted by Claude; for Q audit → Darrell ratify → commit.
>
> **Rule:** a dimension may not enter CAD until its row reads CONFIRMED ✓ (against drawing), MEASURED ✓ (off the part), or COMPUTE-resolved. **Calipers before curves — but read the drawing first.**

**Status legend:** `CONFIRM` published on a manufacturer drawing — verify your part matches · `MEASURED ✓` value already in hand · `MEASURE` no drawing exists, calipers required · `WEIGH` needs scale + mass mock-up · `COMPUTE` derived from other rows/decisions · `GATED` can't be taken until a named OPEN DECISION is made first.

> **Bench session 2026-07-25 — drive corner MEASURED off the real parts:** motor OD **24.79** · M3 hole spacing **16.63** (confirmed two ways: direct + edge-to-body) · boss **6.93 Ø × 2.42 tall** · overall length **66.51** (silver body ~52 / integrated encoder cap ~14.5) · collet stack **12.98** · wheel OD **80.30** → axle Z **40.15** · tire **8.78 full / 7.03 contact** (crowned) · computed track **~171**. §A rows below promoted CONFIRM/MEASURE → MEASURED ✓.

**Source tags / drawings (pull these before the bench session):**
- `[PL-25D]` Pololu 25D gearmotor dimension diagram — https://www.pololu.com/product/4885 → "dimension diagram (PDF)"
- `[PL-3690]` Pololu 80×10 multi-hub wheel — https://www.pololu.com/product/3690
- `[PL-2692]` Pololu 1″ ball caster — https://www.pololu.com/product/2692
- `[PL-5387]` Pololu reverse-voltage protector — https://www.pololu.com/product/5387
- `[RPI3]` Raspberry Pi 3 B official mechanical drawing — https://datasheets.raspberrypi.com/rpi3/raspberry-pi-3-b-mechanical-drawing.pdf
- `[PL-3692]` Pololu VL53L4CD cliff ToF carrier — https://www.pololu.com/product/3692
- `[ADA-####]` Adafruit product page per breakout (5396 = forward/ridge ToF, 713 TB6612, 2858 buck, 5626 mux, 1085 ADS1115)
- `[ZEEE]` Zeee 2200mAh 3S listing (75×34×26.5, confirmed)
- `[BENCH]` no drawing can give it — measure/weigh on YOUR assembled build

---

## A. Drive — motor / cradle / wheels / track

| Measurement | Why CAD needs it | Tool / method | Status | Blocks | Source |
|---|---|---|---|---|---|
| #4885 faceplate: M3 hole spacing + boss Ø + boss height | cradle bolt pattern + pilot bore + pocket depth | **caliper, bench** | **MEASURED ✓ spacing 16.63 · boss Ø 6.93 · boss ht 2.42** | cradle, deck Z | `[BENCH]` |
| Cradle screw depth limit | bolts can't hit gears | drawing note: **≤6 mm into faceplate holes** | CONFIRMED ✓ | cradle bolt spec | `[PL-25D]` |
| #4885 body OD + overall length | cradle cup ID + inboard reach | **caliper, bench** | **MEASURED ✓ OD 24.79 · overall 66.51** (silver body ~52 + encoder cap ~14.5) | cradle, motor-sandwich gap | `[BENCH]` |
| Encoder tail cap (rear) length | rear clearance + motor-wire exit | **caliper, bench** | **MEASURED ✓ ~14.5** — integrated tail cap, no separate protrusion; cradle leaves rear open | cradle rear clearance, wire channel | `[BENCH]` |
| Shaft 4 mm D, extends 12.5 mm from faceplate | collet engagement + wheel offset | diagram | CONFIRMED ✓ | wheel track | `[PL-25D]` |
| **Collet stack width** (faceplate → outer wheel face), #3690 on shaft | sets **wheel track** + the center gap | assembled, **caliper** | **MEASURED ✓ 12.98** | track, gap, side cutouts, plate | `[BENCH]` |
| Wheel OD + tire width **with silicone tire** | side-cutout size, ground clearance, axle Z | **caliper assembled wheel** | **MEASURED ✓ OD 80.30 (→ axle Z 40.15) · tire 8.78 full / 7.03 contact (crowned)** | cutouts, clearance, shell Z | `[BENCH]` |
| **Wheel track** (contact-line to contact-line) | drive geometry / straight tracking | COMPUTE from collet + tire + body width | **COMPUTE ~171** — contact 8.59 outboard of faceplate; flush in 180-wide body (provisional on body width + flush-mount choice) | plate, side cutouts, PASS_2 | design |

## B. Battery + access

| Measurement | Why CAD needs it | Tool / method | Status | Blocks | Source |
|---|---|---|---|---|---|
| Battery L×W×H (75 × 34 × 26.5) | battery-well size | listing value, confirm pack | CONFIRM | well, basement | `[ZEEE]` |
| Battery **swell margin** (soft case) | clearance so an aged/charged pack still fits | add ~1–2 mm over measured | MEASURE | well clearance | `[BENCH]` |
| XT60 body + lead exit + **unplug finger room** | serviceable disconnect (Q #2) | caliper + hand test | MEASURE | corridor, well orientation | `[BENCH]` |
| Balance-lead length + plug + LiPo-alarm body | alarm reachable while strapped (Q #7) | measure lead + alarm | MEASURE | well, alarm access | `[BENCH]` |
| Strap path + strap width | strap must not crush wiring (Q #1) | layout test w/ strap | MEASURE | well, wire routing | `[BENCH]` |
| Battery-door aperture + removal direction | door opening + clearance arc | derive AFTER door-side chosen | **GATED** (battery-door decision) | battery door — V1-BLOCKING | `[BENCH]` post-decision |
| **Component masses + assembled CG** (mass mock-up) | proves battery final X / no-tip — *the PASS_1 §4.2 gate* | scale each part + balance mock-up | **WEIGH** | **battery final X, CG sign-off, PASS_2** | `[BENCH]` |

## C. Compute — Pi 3

| Measurement | Why CAD needs it | Tool / method | Status | Blocks | Source |
|---|---|---|---|---|---|
| Pi PCB 85 × 56 + M2.5 mounting-hole pattern | mount holes + cabin plan | drawing confirm | CONFIRM | Pi mount, cabin | `[RPI3]` |
| Pi connector Z-heights (**tallest = 16.0 mm**, USB/Eth) | cabin height, thermal gap | drawing confirm | CONFIRM | cabin/shell Z, thermal | `[RPI3]` |
| Pi port X/Y positions (USB / Eth / µUSB / HDMI / GPIO / CSI / **SD**) | service cutouts, **SD access** (Q #3) | drawing confirm | CONFIRM | orientation, hatch, SD cut | `[RPI3]` |
| **Installed stack height** (YOUR standoff + 1.4 board + 16 connector) | cabin/shell Z, deck-Z confirm | **caliper assembled w/ your standoffs** | **MEASURE** | cabin/shell Z | `[BENCH]` |
| Min air gap over tallest Pi component | thermal path (§4.6) | choose gap, confirm vs 16.0 | COMPUTE | Pi thermal architecture | `[RPI3]`+design |

## D. Cliff bay

| Measurement | Why CAD needs it | Tool / method | Status | Blocks | Source |
|---|---|---|---|---|---|
| VL53L4CD (Pololu #3692) cliff carrier L×W×H + mount hole | pocket size + fixed-height mount | product page confirm | CONFIRM | cliff-bay pockets | `[PL-3692]` |
| ToF cable exit + min bend radius (STEMMA/Qwiic) | cable can't fold sharp into plate (Q #4) | measure connector + cable | MEASURE | bay, wire channel | `[BENCH]` |
| Optical-window aperture + ToF-to-floor baseline | cone clearance + lookahead geometry | compute from FoV + mount Z | COMPUTE | bay, nose window, cliff-X | design |
| Cliff-X offset (≥50 mm lookahead point) | the rule → real plate X | compute from baseline + FoV + speed | COMPUTE | cliff-bay X, plate | design |

## E. Caster (rear support)

| Measurement | Why CAD needs it | Tool / method | Status | Blocks | Source |
|---|---|---|---|---|---|
| Caster #2692 overall height + 3× M3 base pattern | pod/shim height + mount holes | spec, confirm in-hand | **MEASURED ✓ (29 mm)** | caster pod | `[PL-2692]` |
| Pod/shim height = deck-Z − 29 | level deck (cradle → deck Z → pod → level check) | compute after deck Z resolves | COMPUTE | caster pod, level-deck verification | design |

## F. Power / service corridor

| Measurement | Why CAD needs it | Tool / method | Status | Blocks | Source |
|---|---|---|---|---|---|
| Board dims + connector heights: TB6612, buck, PCA9548, ADS1115, hub, shifters | electronics-tier packing + corridor | product pages, confirm | CONFIRM | cabin tier, rear corridor | `[ADA-713/2858/5626/1085]` |
| #5387 protector board dims | corridor placement | product page confirm | CONFIRM | rear corridor | `[PL-5387]` |
| Fuse holder + access clearance | replace w/o pulling battery or deck (Q #6) | measure holder + access path | MEASURE | corridor, fuse access | `[BENCH]` |
| Rocker switch body + 19×13 panel cutout (F4) | panel cutout missing from CAD | caliper KCD1-101 | MEASURE | rear/side panel, F4 | `[BENCH]` |

## G. Wire channels + frame fasteners

| Measurement | Why CAD needs it | Tool / method | Status | Blocks | Source |
|---|---|---|---|---|---|
| Wire-channel width/depth per bundle + min bend radius | channel sizing + strain relief | compute from bundle Ø + connector bend specs | COMPUTE | plate, core frame, channels | design |
| Heat-set insert (ruthex M3) boss Ø + depth | boss sizing for melt-in inserts | ruthex spec + test print | CONFIRM | all printed bosses | ruthex spec |
| M3 fastener head Ø + clearance (VGBUY) | counterbore / clearance holes | spec / caliper | CONFIRM | frame fasteners | VGBUY spec |
| Insert/boss edge wall thickness | wall around inserts won't split | **test print + measure** | MEASURE | core frame, plate | `[BENCH]` |

---

## What the drawings already settle (no bench time needed beyond a confirm)

Pulled this session, treat as CONFIRM-against-drawing, not blind measure:
- **Motor #4885** — now **MEASURED off the part** (bench 2026-07-25): OD 24.79 · M3 spacing 16.63 · boss 6.93 Ø × 2.42 · overall 66.51 (silver ~52 / cap ~14.5). Shaft 4 mm D out 12.5 & **≤6 mm screw depth** still per `[PL-25D]`.
- **Pi 3** — 85 × 56 PCB, standard M2.5 hole pattern, **tallest connector 16.0 mm**. All on `[RPI3]`.
- **Caster #2692** — 29 mm, 3× M3. `[PL-2692]`. **MEASURED ✓.**
- **Battery** — 75 × 34 × 26.5. `[ZEEE]`.

## What NO drawing can give you (true bench work)

1. **Installed Pi stack** — depends on YOUR standoffs, not Pi's drawing.
2. **LiPo swell** — soft-case packs grow; design clearance above the listed 26.5.
3. **Wheel OD with the silicone tire on** — molded tire runs off-nominal.
4. **Collet stack / wheel-face offset on your shaft** — the fit that sets track.
5. **Assembled masses + CG** — the PASS_1 mock-up; no drawing exists.
6. **Fit clearances** — XT60 finger room, cable bend radius in your channels, fuse-access path, boss wall thickness.

## Falsifier additions (not on the original list)

1. **Component masses + CG (§B, WEIGH).** Q's PASS_1 audit made battery final-X contingent on a mass mock-up, but the gate prompt omitted it. The single most load-bearing number CAD can't guess — it converts the aft-window battery from *proposed* to *proven*. Bridge to PASS_2.
2. **Wheel actual OD + width incl. tire (§A, MEASURE).** The list skipped the wheel's own outer dimension; silicone runs off-nominal and it sets cutout + clearance + protrusion at once.

## Dependency note (one item is not a pure measurement)

**Battery-door aperture is GATED, not MEASURE** — uncalipherable until the door-side / removal-direction decision (an OPEN DECISION, V1-BLOCKING) is made first. Filed gated so it isn't mistaken for a bench number waiting to be read.

## What this gate unblocks, in priority order

- **One #4885 bench session unblocks three things:** faceplate + boss → cradle spec; body/encoder → cradle clearance; **collet stack → wheel track → the whole motor-sandwich gap and the deck-Z chain.** Highest-leverage measurement in the build. (Most of the motor's own dims are already CONFIRM via `[PL-25D]` — the only true bench number here is the collet stack.)
- **The CG mass mock-up unblocks the battery's final position** and clears the PASS_1 §4.2 condition for CAD.
- **Installed Pi stack firms the cabin/shell Z** (the soft ~90).
- Everything else is parallel; none CAD-drawable until its row resolves.

*Calipers before curves — but read the drawing first. The gate holds the pencil back until the part has spoken.*

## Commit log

2026-06-15 Initial QD electronics inventory + flags roadmap
    [QD_Electronics_Inventory.xlsx, QD_Flags.csv, QD_Inventory.csv]
2026-06-15 Add V1 BOM and brain-body interface stub specs
2026-06-15 Add V1 schematic pass 1
2026-06-16 Update V1 schematic: cliff sensing resolved to downward ToF, reverse protector #5387, parts ordered
2026-06-17 Add V1 master footprint and bottom-plate constraints (Q-checked + Darrell Z-section/caster catches logged)
2026-06-17 v1.1: amend footprint spec — front-module datum + cone-clearance rule, KB2040/load-disconnect/Pi-UPS reservations, two-ToF safety non-claim, motor-mount OPEN DECISION (gates deck height), cliff-verti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
2026-06-18 v1.2: kill 72mm cap (derived shell ~90mm), demote envelope to provisional under design hierarchy, lock motor mount = printed cradle (deck ~57, clearance 27.5), add ToF reflectance bench-validation cl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
2026-06-18 Schematic pass 1: correct cliff-ToF overclaim — ToF reduces reflectance dependence vs IR but tile/carpet/drop-off still needs bench validation (watch-word fix, per Q audit)
2026-06-18 Inventory: add WS2812B LED band + 3.3-to-5V level shifter (rows 94-95)
    [QD_Electronics_Inventory.xlsx]
2026-06-19 Sync BOM + CAD-gate: cliff ToF = Pololu #3692 (not #5396), forward/cliff pairs split, received parts BUY->HAVE
2026-07-25 CAD gate: land measured drive-corner numbers (motor, wheel, track) from 2026-07-25 bench
2026-07-25 Add V1 cradle spec pass 1 (fit-test coupon) — Q-audited, face-mount + slip saddle
2026-07-26 Add Coupon Rev A modeling recipe (traces to cradle spec f6377c7)
2026-07-26 Add Coupon Rev A OpenSCAD model
    [coupon_revA.scad]
2026-07-26 Coupon Rev A: FIT_VERIFIED - all 6 checks pass, 2x M3x8 mount
2026-07-26 Cradle spec Pass 2 rev 2: strap compression-stop, non-powered torque test, quantified load vectors, split structure gates, slot anti-slip (Q Pass-2 audit)
2026-07-27 Add Coupon Rev A STL (the printed, FIT_VERIFIED geometry)
    [coupon_revA.stl]
2026-07-27 Cradle Pass 2: retention RATIFIED by Darrell - 180 saddle + compression-limited strap
2026-07-27 Add Pass-2 cradle CAD recipe + prototype model (cradle/strap/fixture), traces to 05e382b
    [cradle_pass2_proto.scad]
2026-08-04 Ratify Pi 5 as QD Stage-1 compute platform
2026-08-04 Ratify fixed 55–65 mm stereo sensing for QD Stage 1
2026-08-04 Record QD Stage-1 sensing architecture Revision 3
2026-08-04 Ratify complete QD Stage-1 sensor lineup

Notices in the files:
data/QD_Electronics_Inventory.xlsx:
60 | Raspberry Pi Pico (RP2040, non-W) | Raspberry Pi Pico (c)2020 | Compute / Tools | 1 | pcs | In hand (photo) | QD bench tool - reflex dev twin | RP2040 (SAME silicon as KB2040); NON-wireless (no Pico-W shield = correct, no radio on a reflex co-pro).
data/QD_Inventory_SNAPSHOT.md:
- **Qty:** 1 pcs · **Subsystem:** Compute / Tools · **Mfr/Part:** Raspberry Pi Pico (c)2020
